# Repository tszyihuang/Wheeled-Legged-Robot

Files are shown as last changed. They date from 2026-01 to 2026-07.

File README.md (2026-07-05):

0c5eb42da822242b4dad09033252d7c5
86a04491187a1cce568d0ce1c19f64d7

## 🛠️ 物料清单 (Bill of Materials)

### ⚙️ 机械与动力组件
| 部件名称 | 规格/型号 | 数量 | 备注/说明 |
| :--- | :--- | :--- | :--- |
| **舵机** | MG996R (180度) | 4 | 用于腿部关节驱动 |
| **无刷电机** | 2208 (带磁编码器) | 2 | 轮毂动力，需配合轮胎安装 |
| **轮胎** | 6030-6085 | 2 | 直径/宽度规格，适配 2208 电机 |
| **轴承** | 6701zz | 6 | 尺寸: 12x18x4mm，用于关节转动轴 |

### 🔩 紧固件与辅材
| 部件名称 | 规格 | 数量 | 备注 |
| :--- | :--- | :--- | :--- |
| **螺丝** | M3 (长度需根据装配补充) | 若干 | 建议准备 M3 螺丝包 (6mm-20mm) |
| **螺丝** | M2 (长度需根据装配补充) | 若干 | 用于固定电子件或小结构 |
| **打印件** | 自制 | 1套 | 详见 `/STL_Files` 文件夹 |

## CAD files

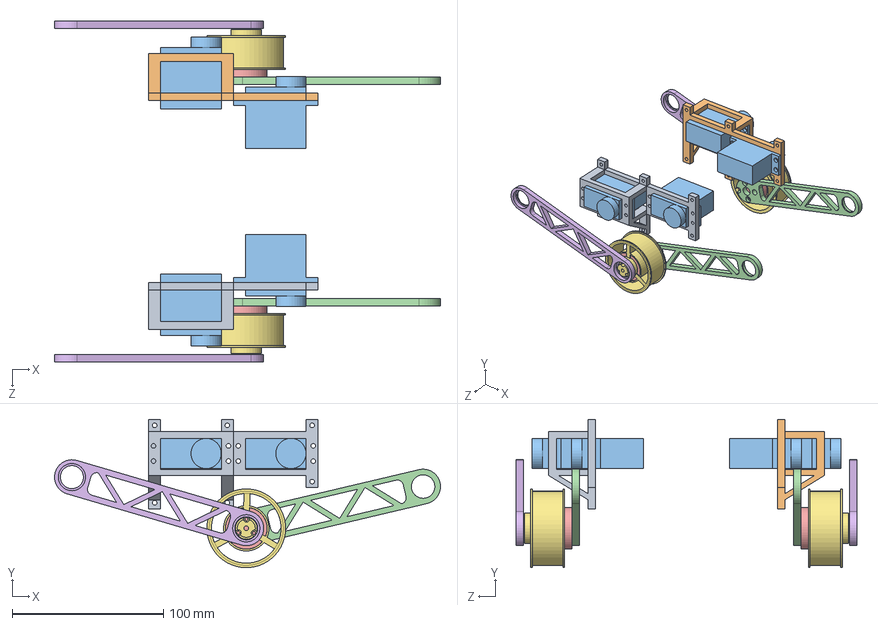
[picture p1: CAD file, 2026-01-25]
机械结构/Assem.SLDASM
254.9 x 98.0 x 225.0 mm
轮毂 x 2
外侧小腿 x 2
电机 x 2
内侧小腿 x 2
舵机 x 4
髋关节
髋关节mirrod

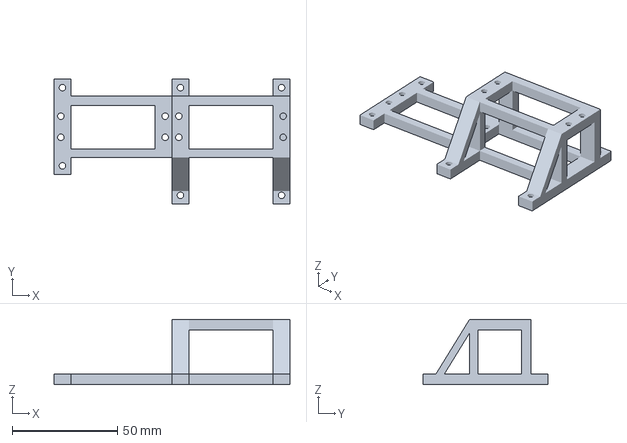
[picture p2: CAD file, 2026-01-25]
打印文件/右-髋关节.3MF
112.0 x 59.1 x 31.0 mm

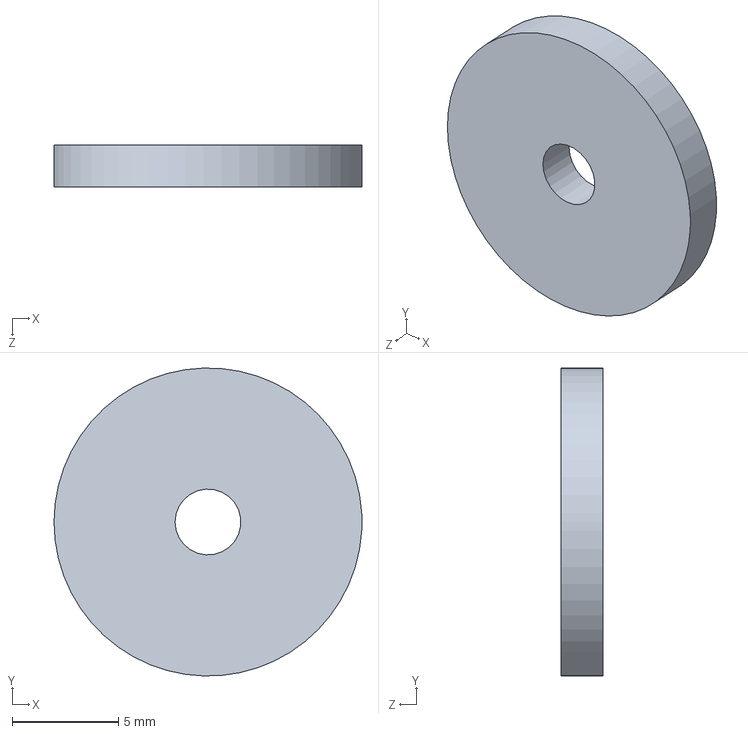
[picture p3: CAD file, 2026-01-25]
机械结构/轴承盖板.SLDPRT
14.5 x 14.5 x 2.00 mm

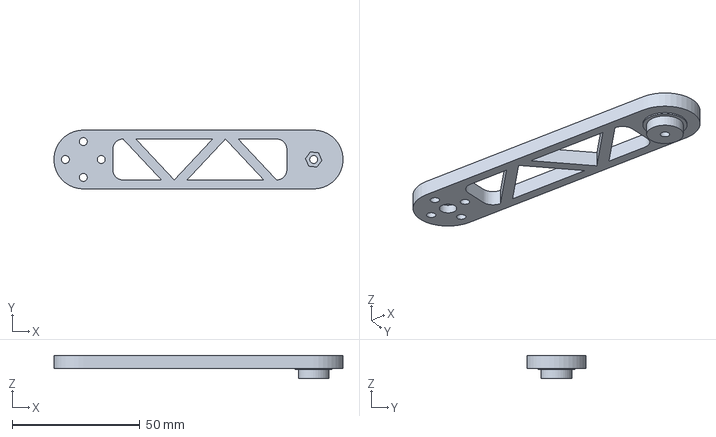
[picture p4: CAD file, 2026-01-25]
打印文件/左-内侧大腿.3MF
112.9 x 23.0 x 9.00 mm

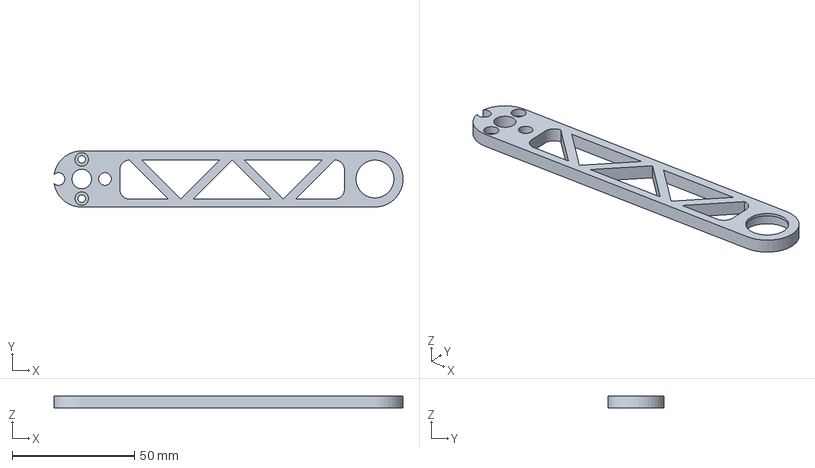
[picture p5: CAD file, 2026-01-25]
打印文件/左-内侧小腿.3MF
142.8 x 23.0 x 5.00 mm

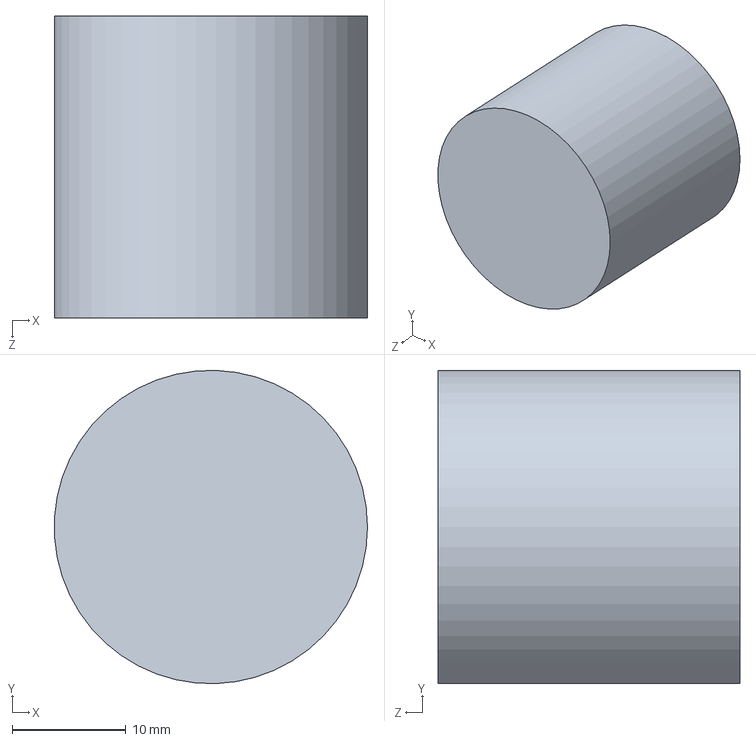
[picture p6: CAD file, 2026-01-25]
机械结构/电机.SLDPRT
27.5 x 27.5 x 26.5 mm

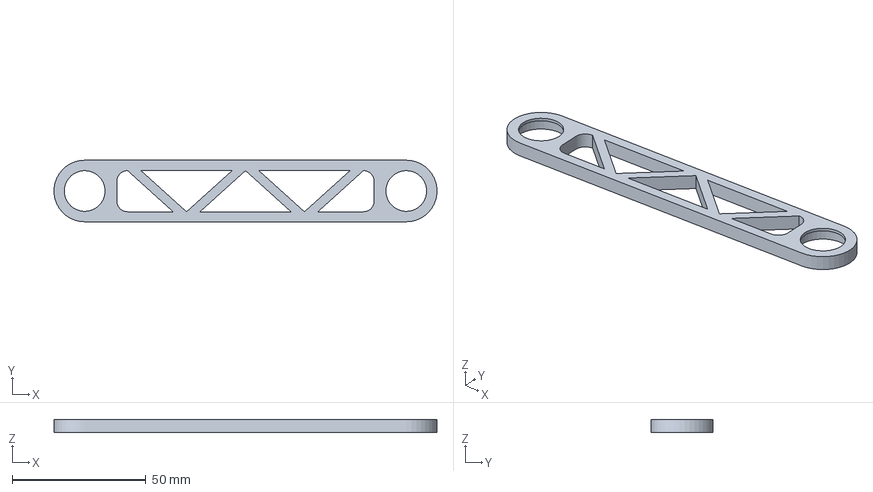
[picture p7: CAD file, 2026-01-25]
打印文件/右-外侧小腿.3MF
142.9 x 23.0 x 5.00 mm

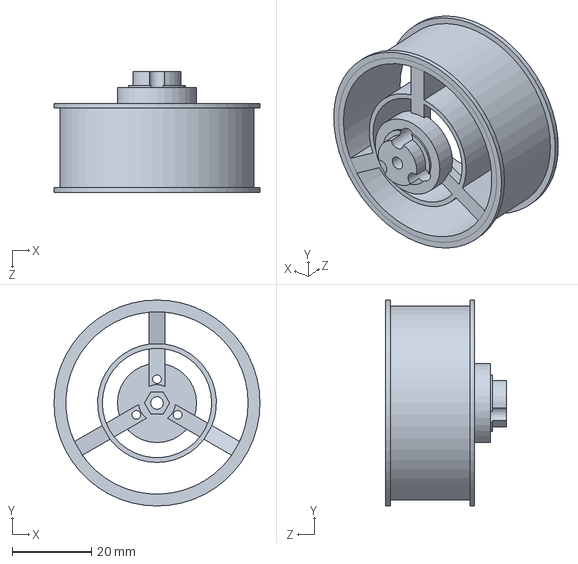
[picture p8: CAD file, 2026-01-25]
机械结构/轮毂.SLDPRT
52.0 x 52.0 x 30.5 mm

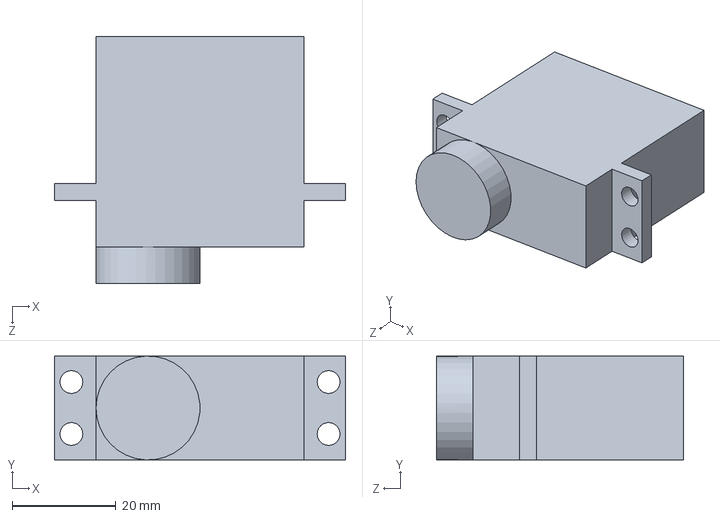
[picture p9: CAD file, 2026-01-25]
机械结构/舵机.SLDPRT
56.0 x 20.0 x 47.5 mm

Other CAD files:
机械结构/髋关节mirrod.SLDPRT
打印文件/左-外侧大腿.3MF
机械结构/髋关节.SLDPRT
机械结构/外侧小腿.SLDPRT
打印文件/右-内侧小腿.3MF
机械结构/内侧小腿.SLDPRT
打印文件/轴承盖板.3MF
打印文件/右-内侧大腿.3MF
打印文件/右-外侧大腿.3MF
打印文件/左-外侧小腿.3MF
打印文件/底盘.3MF
打印文件/轮毂.3MF
机械结构/内侧大腿.SLDPRT
机械结构/外侧大腿.SLDPRT
机械结构/底盘.SLDPRT

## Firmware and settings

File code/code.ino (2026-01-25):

/**
 * ESP32-S3 平衡轮腿机器人固件
 * 硬件: ESP32S3, SimpleFOC Mini x2, 2208电机 x2, PCA9685, MPU6050
 */

#include <SimpleFOC.h>
#include <Wire.h>
#include <Adafruit_PWMServoDriver.h>
#include <MPU6050_light.h>

// ================= 1. 定义引脚与对象 =================

// --- I2C 定义 ---
#define I2C0_SDA 1
#define I2C0_SCL 2
#define I2C1_SDA 15
#define I2C1_SCL 16

// --- MPU6050 ---
// 连接在 I2C0
MPU6050 mpu(Wire);
#define MPU_ADO_PIN 6 // 你的 ADO 接了 Pin 6
#define MPU_INT_PIN 7

// --- 舵机 (PCA9685) ---
// 连接在 I2C0
Adafruit_PWMServoDriver servos = Adafruit_PWMServoDriver(0x40);

// --- 电机与驱动 (3PWM模式) ---
// 假设 SimpleFOC Mini 使用 3PWM 控制
// 电机 1 (左?)
BLDCMotor motor1 = BLDCMotor(7); // 2208电机通常是7对极，请确认
BLDCDriver3PWM driver1 = BLDCDriver3PWM(40, 41, 42); 
// 编码器 1 (AS5600等 I2C磁编码器，连接在 I2C0)
MagneticSensorI2C sensor1 = MagneticSensorI2C(AS5600_I2C);

// 电机 2 (右?)
BLDCMotor motor2 = BLDCMotor(7); 
BLDCDriver3PWM driver2 = BLDCDriver3PWM(39, 38, 37);
// 编码器 2 (连接在 I2C1)
MagneticSensorI2C sensor2 = MagneticSensorI2C(AS5600_I2C);

// ================= 2. 控制参数 =================

// --- 直立环 (Stabilization) ---
// 目标：保持 Pitch 角度为 0 (或由速度环给出的偏移量)
// 你测试过的参数: P=10, D=0.2
PIDController pid_stb(6, 0, 0.02, 10000, 20); // P, I, D, Ramp, Limit

// --- 速度环 (Velocity) ---
// 目标：保持车轮转速为 0
PIDController pid_vel(0.05, 0.005, 0, 1000, 10); // 需要调试，先给小值
LowPassFilter lpf_vel(0.1); // 速度低通滤波

// --- 变量 ---
float target_pitch = 0; // 目标角度
float pitch_offset = 1.6; // 机械平衡零点偏移(如果车重心不正，调整此值)
float target_speed = 0; // 目标速度 (0 = 静止)
float steering = 0;     // 转向分量

// --- 调参命令 ---
Commander command = Commander(Serial);
void doPIDStb(char* cmd) { command.pid(&pid_stb, cmd); }
void doPIDVel(char* cmd) { command.pid(&pid_vel, cmd); }
void doTarget(char* cmd) { command.scalar(&target_speed, cmd); }
void doOffset(char* cmd) { command.scalar(&pitch_offset, cmd); }
// ================= 3. 辅助函数 =================

// 将 0-180度 映射到 120-480 脉冲宽
void setServoAngle(uint8_t n, double angle) {
  if (angle < 0) angle = 0;
  if (angle > 180) angle = 180;
  // 映射: 0->120, 180->480
  int pulse = map(angle, 0, 180, 120, 480);
  servos.setPWM(n, 0, pulse);
}

// ================= 4. Setup 初始化 =================

void setup() {
  Serial.begin(115200);
  delay(1000);
  Serial.println("System Init Start...");

  // --- I2C 总线初始化 ---
  // Wire (I2C0): MPU6050, Servo, Sensor1
  Wire.setPins(I2C0_SDA, I2C0_SCL);
  Wire.begin();
  
  // Wire1 (I2C1): Sensor2
  Wire1.setPins(I2C1_SDA, I2C1_SCL);
  Wire1.begin();

  // --- 1. MPU6050 初始化 ---
  // 设置 ADO 引脚为 LOW，确保地址是 0x68 (默认)
  pinMode(MPU_ADO_PIN, OUTPUT);
  digitalWrite(MPU_ADO_PIN, LOW); 
  
  byte status = mpu.begin();
  Serial.print("MPU6050 status: "); Serial.println(status);
  Serial.println("Calibrating MPU6050... Keep robot still!");
  mpu.calcOffsets(); // 启动时校准，保持静止！
  Serial.println("MPU6050 Ready.");

  // --- 2. 舵机初始化 ---
  servos.begin();
  servos.setPWMFreq(50); // 模拟舵机频率 50Hz
  delay(10);
  // 锁定舵机角度
  // 0路:90度, 1路:85度, 2路:95度, 3路:90度
  setServoAngle(0, 90);
  setServoAngle(1, 100);
  setServoAngle(2, 110);
  setServoAngle(3, 100);
  Serial.println("Servos Locked.");

  // --- 3. SimpleFOC 电机初始化 ---
  
  // 传感器 1
  sensor1.init(&Wire);
  motor1.linkSensor(&sensor1);
  
  // 驱动 1
  driver1.voltage_power_supply = 12; // 假设12V供电，请根据实际修改
  driver1.init();
  motor1.linkDriver(&driver1);

  // 传感器 2 (注意这里用 Wire1)
  sensor2.init(&Wire1);
  motor2.linkSensor(&sensor2);

  // 驱动 2
  driver2.voltage_power_supply = 12; 
  driver2.init();
  motor2.linkDriver(&driver2);

  // 电机控制模式：力矩(电压)控制
  motor1.controller = MotionControlType::torque;
  motor2.controller = MotionControlType::torque;

  // 启用监控 (调试用，正式跑可以注释掉)
  // motor1.useMonitoring(Serial);

  // 初始化电机
  motor1.init();
  motor2.init();

  // 校准磁编码器零点 (FOC init)
  Serial.println("Aligning Motor 1...");
  motor1.initFOC(); 
  Serial.println("Aligning Motor 2...");
  motor2.initFOC();

  // --- 4. 串口命令设置 ---
  command.add('S', doPIDStb, "Stabilize PID"); // 输入 SA10 设置 P=10
  command.add('V', doPIDVel, "Velocity PID");  // 输入 VP0.1 设置 P=0.1
  command.add('T', doTarget, "Target Speed");  // 输入 T0 停止
  command.add('O', doOffset, "Motion Zero Offset");
  Serial.println("Ready for Balancing!");
}

// ================= 5. Main Loop =================

long loop_count = 0;
float voltage_control = 0;

void loop() {
  // 1. FOC 核心循环 (必须尽可能快地运行)
  motor1.loopFOC();
  motor2.loopFOC();

  // 2. 控制逻辑 (由于 MPU 读取较慢，我们降频运行控制环，例如每 5ms 一次)
  // 或者直接运行，但在 loopFOC 之间插入
  static unsigned long last_process_time = 0;
  if (millis() - last_process_time >= 5) { // 200Hz 控制频率
    last_process_time = millis();

    // A. 读取数据
    mpu.update(); 
    float pitch = mpu.getAngleY(); // 假设 Y 轴是你的 Pitch 轴
    float gyro_rate = mpu.getGyroY(); // 角速度

    // 获取电机速度 (弧度/秒)
    float v1 = motor1.shaft_velocity;
    float v2 = motor2.shaft_velocity;
    float avg_speed = (v1 + v2) / 2.0; // 平均速度
    
    // 速度滤波
    float current_speed = lpf_vel(avg_speed);

    // B. 速度环 (外环)
    // 输入：速度误差 (目标速度 - 当前速度)
    // 输出：目标倾角 (要想加速，就得前倾)
    // 这里的 target_speed 通常为 0 (原地站立)
    float target_angle_raw = pid_vel(target_speed - current_speed);
    
    // 限制目标倾角，防止速度环要求过大的倾斜导致倒地 (例如限制在 +/- 15度)
    target_angle_raw = constrain(target_angle_raw, -15, 15);

    // C. 直立环 (内环)
    // 输入：角度误差 (目标角度 - (当前角度 - 机械零点))
    // 注意：如果向前倒 (Pitch > 0)，需要正向转矩冲过去
    float balance_control = pid_stb((target_angle_raw + pitch_offset) - pitch);

    // 如果倒下太厉害 (超过40度)，关闭电机保护
    if (abs(pitch) > 40) {
      voltage_control = 0;
      pid_stb.reset(); // 重置积分项
      pid_vel.reset();
    } else {
      voltage_control = balance_control;
    }
  }

  // 3. 执行电机动作
  // 根据电机安装方向，可能其中一个需要取反
  // 假设 X 正方向前进，如果 pitch>0 (前倾)，voltage 应该 >0 (车轮向前转)
  motor1.move(voltage_control); 
  motor2.move(-voltage_control); // 如果电机2装反了，这里改为 -voltage_control

  // 4. 串口命令监听
  command.run();
}

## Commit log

2026-07-05 加了实物图
2026-07-05 改了图片大小
2026-09-15 添加 MIT 许可证
2026-09-15 更正许可证署名
